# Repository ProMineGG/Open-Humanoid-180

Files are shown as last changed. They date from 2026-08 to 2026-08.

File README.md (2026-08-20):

# Open-Humanoid-180





[Дорожная карта проекта](https://github.com/ProMineGG/Open-Humanoid-180/issues/1)
[Contributing](CONTRIBUTING.md)

*Читать на других языках: [English](README.en.md)*

**Открытый проект двуногого гуманоидного робота ростом 180 см — на доступных компонентах, самодельных волновых редукторах и распределённой вычислительной архитектуре.**

---

## Обзор

Цель проекта — создать полноразмерного (180 см, ~60 кг) шагающего робота с бортовым ИИ (зрение + языковые модели) при бюджете около **350 тыс. рублей**.  
Вместо дорогих промышленных приводов используются:

- Самодельные **двухступенчатые волновые редукторы с промежуточными телами качения (ПТК)** — стальные ролики от подшипников в качестве тел качения.  
- **BLDC-моторы** четырёх типов (6384, 5065, 5010, 3205) — всего 36 степеней свободы.
- **Ноутбук с RTX 3080** без корпуса — основной мозг (альтернатива дорогим специализированным модулям, обеспечивая большую доступность и производительность за цену).
- **Распределённая сеть управления:** ESP32-S3 как CAN-шлюз, AT32F403ACGU7 для низкоуровневого FOC, перепрошитые платы от гироскутеров для средних и базовых моторов.

Все механические детали рассчитаны на **литьё алюминия в самодельной печи** (угольный горн) или 3D-печать (PETG / PETG-CF) на Ender 3 V3 Plus.

---

## Основные характеристики

| Параметр | Значение |
| :--- | :--- |
| Рост / Вес | 180 см / ~60 кг (целевой) |
| Степени свободы | 36 (6 мощных + 7 средних + 10 базовых + 13 слабых) |
| Аккумулятор | 10S Li‑NMC (SK 3.7В 80.5Ач) + JK Smart BMS (200А) |
| Основная шина питания  | 33-41В(вольтаж на ячейку ограничен 3.3-4.1В) |
| Вторичные напряжения | 24В (SimpleFOCmini), 20 В (ноутбук), 5 В (логика + экран) |
| Вычисления | Ноутбук Lenovo L7 / R9 / RTX 3080 / 32GB / 1TB (Ubuntu 22.04 + RT‑Preempt) |
| Узел реального времени | ESP32‑S3 (CAN-шлюз, сбор IMU, расширение ввода/вывода) |
| Контроллеры моторов | ODrive3.6 (x3), Платы гироскутеров (x9), SimpleFOCMini (x13) |
| Связь | CAN (STM32F103C8T6+SN65HVD230) |
| Датчики | 13× BMI160, 1× ICM-20948, 10× FSR402, 4× тензодатчика XNQJALYCY 100кг |
| Бюджет (август 2026) | ~329 043 ₽ (подробно в [BOM.ru.md](./docs/BOM.ru.md)) |
| Лицензия | **GNU GPLv3** (код, CAD, схемы) |

---

## Компоновка приводов и редукторы

Механика построена по модульному принципу. Распределение моторов по суставам:

- **Ноги (8 приводов):**  
  – **6× 6384 120KV** (редукция 1:100) – по 2 на каждый тазобедренный сустав (сгибание/отведение) + по 1 на колено.  
  – **2× 5010 360KV** (редукция 1:64) – вращение в тазобедренных суставах (по одному на ногу).

- **Корпус и шея (4 привода):**  
  – **1× 5065 140KV** (1:64) – наклон корпуса (поясница).  
  – **3× 3205 110KV** (1:42) – шея (2 наклона + 1 поворот).

- **Руки (24 привода):**  
  – **4× 5065 140KV** (1:64) – плечи (по 2 на руку: подъём и отведение).  
  – **2× 5010 360KV** (1:42) – плечи (вращение, по 1 на руку).  
  – **2× 5065 140KV** (1:64) – локти (сгибание, по 1 на руку).  
  – **2× 5010 360KV** (1:42) – локти (вращение предплечья, по 1 на руку).  
  – **4× 5010 360KV** (1:42) – запястья (по 2 на руку: сгибание/отведение, приводы вынесены в предплечья с тросами Боудена).  
  – **10× 3205 110KV** (1:42) – пальцы (по 5 на руку, сгибание).

**Итого:**  
- 6384 – 6 шт.  
- 5065 – 7 шт. (4 плечи + 2 локти + 1 поясница)  
- 5010 – 10 шт. (2 таз + 2 плечи вращ. + 2 локти вращ. + 4 запястья)  
- 3205 – 13 шт. (3 шея + 10 пальцев)

**Редукторы:**  
Самодельные **волновые передачи с роликами (ПТК)**.  
- Двухступенчатая схема; общие передаточные числа:  
  - 1:100 – для мощных (6384)  
  - 1:64 – для средних (5065) и базовых (5010) в тазобедренных суставах  
  - 1:42 – для слабых (3205) и базовых (5010) в плечах, локтях и кистях  
- Тела качения — стандартные стальные ролики от подшипников (дешёвые, износостойкие).  
- Корпуса отливаются из алюминия или печатаются из PETG CF/GF.

### Процесс производства редукторов (DIY Casting)

Для создания волновых редукторов алюминий предварительно переплавляется в очищенные слитки в самодельной печи.

<table align="center" border="0" cellpadding="5" cellspacing="0">
  <tr>
    <td valign="top">
      <table border="0" cellpadding="5" cellspacing="0">
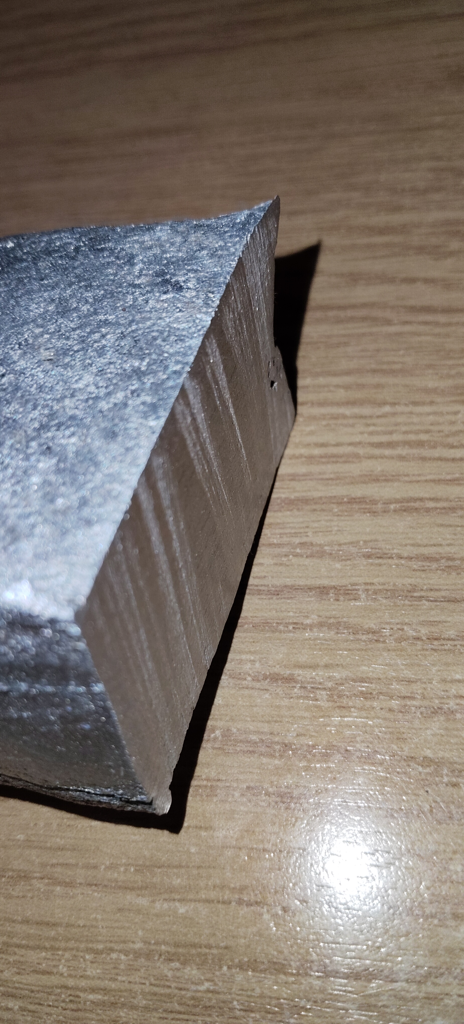
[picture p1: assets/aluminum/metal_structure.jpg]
Срез металла 1
        <tr><td></td></tr>
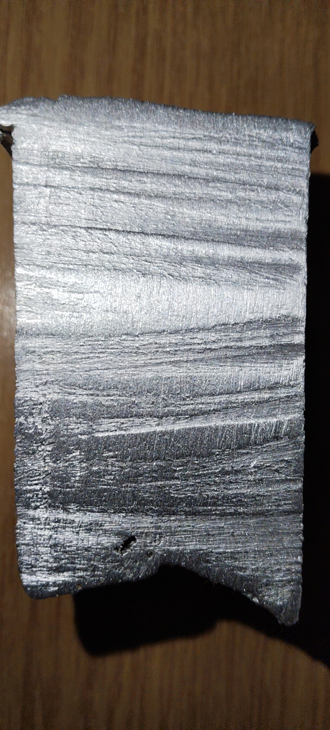
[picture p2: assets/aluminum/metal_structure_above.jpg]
Срез металла 2
        <tr><td></td></tr>
      </table>
    </td>
    <td valign="top">
      <table border="0" cellpadding="5" cellspacing="0">
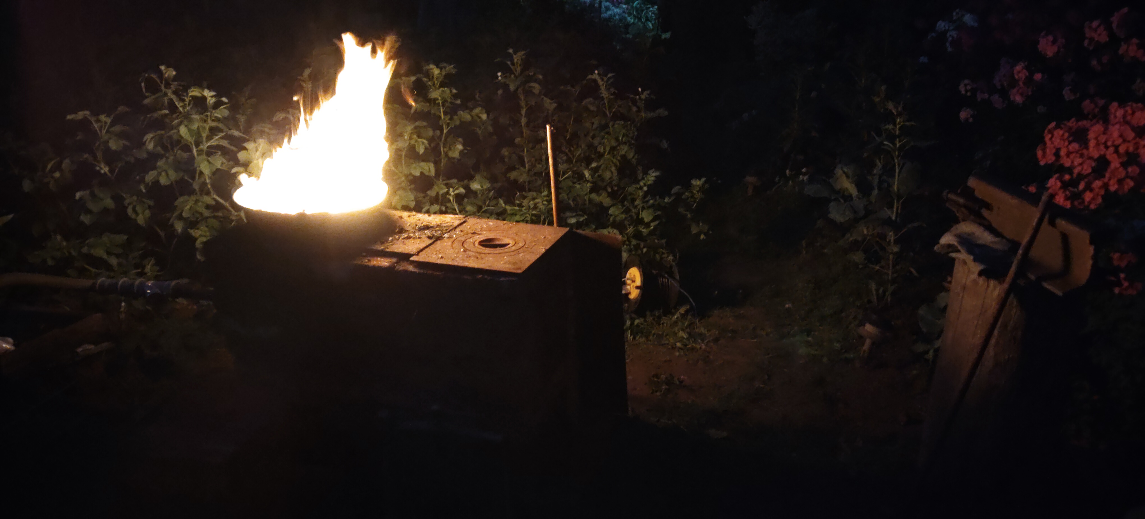
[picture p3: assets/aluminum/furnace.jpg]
Ночная печь
        <tr><td></td></tr>
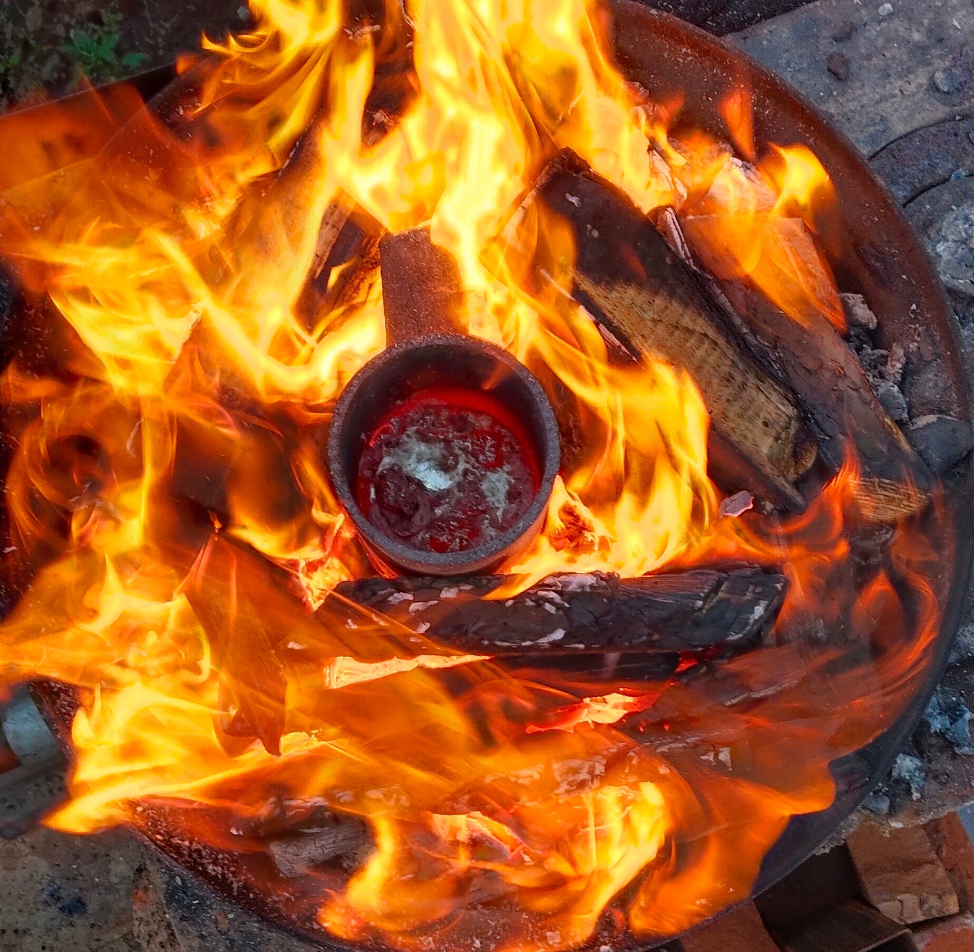
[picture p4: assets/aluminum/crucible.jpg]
Жидкий алюминий в тигле
        <tr><td></td></tr>
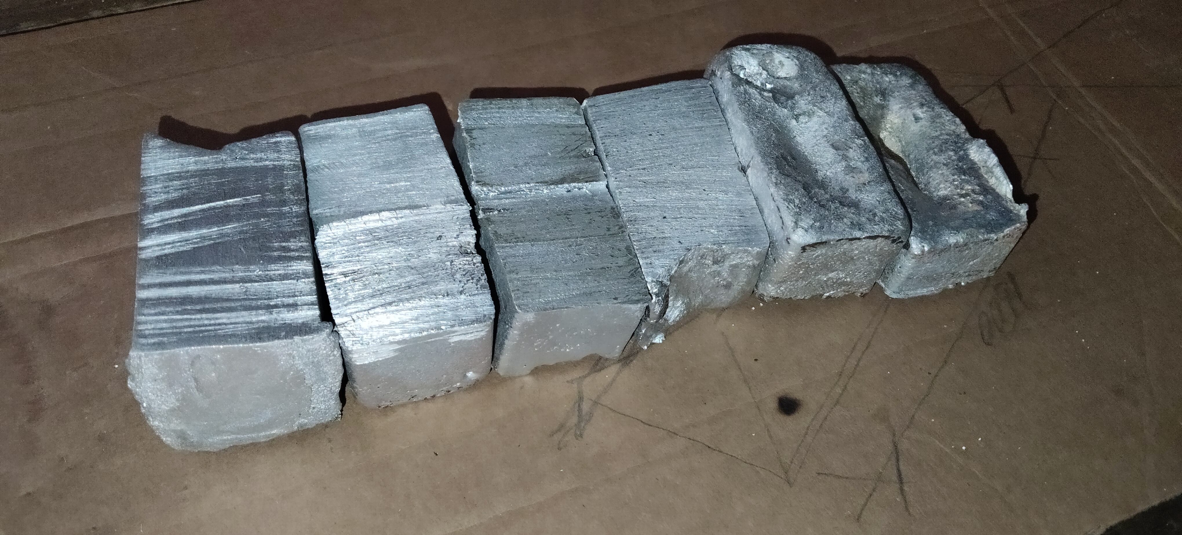
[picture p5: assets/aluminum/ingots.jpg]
Готовые слитки 1
        <tr><td></td></tr>
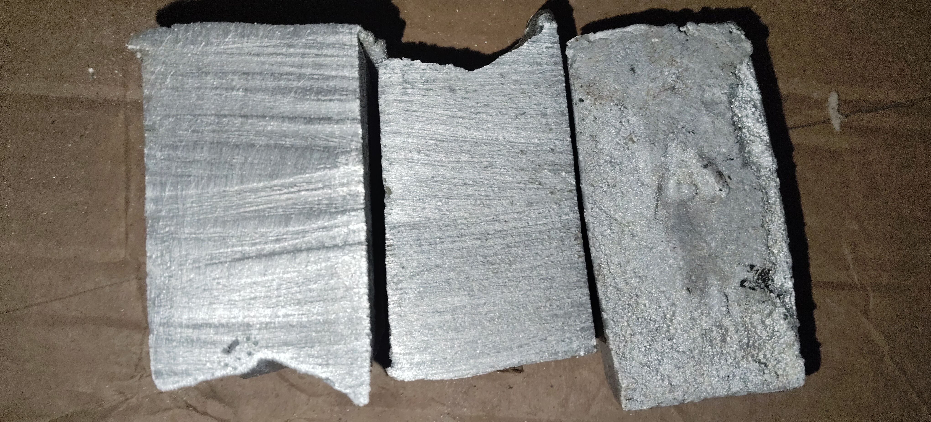
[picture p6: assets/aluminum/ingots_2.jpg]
Готовые слитки 2
        <tr><td></td></tr>
      </table>
    </td>
  </tr>
</table>

---

## Распределение питания и защита

- **Аккумулятор:** 10S Li‑NMC (SK 3.7В 80.5Ач, pouch‑ячейки) – высокая энергоёмкость при умеренном весе.  
- **BMS:** JK‑B2A24S20P (200А постоянный, поддержка 8-24S) с Bluetooth-мониторингом.  
- **Основная защита:** автоматический выключатель 200А на плюсовой линии.  
- **Блок предохранителей:** хаб ATO на 10 гнёзд – 40А для рук/торса, 25А для ноутбука и 5В-преобразователей, 10А для головы.  
- **Отдельные предохранители:** 3 одиночных держателя с предохранителей 80А – каждый для своего ODrive3.6 (питание напрямую от распределительных блоков).  
- **Распределительные блоки:** два блока на 250А (11 выводов) – плюсовая и минусовая шины.  
- **Конденсаторы на шине:** 10× 63В 4700 мкФ, 15× 35В 2200 мкФ – демпфируют выбросы рекуперации.  
- **Локальная фильтрация:** керамика 0.1 мкФ на каждой SPI/I2C-линии и плате драйвера для подавления ШИМ-помех, а также LC-фильтры помех после понижающий преобразователей 5в и 24в
- **Монтаж:** сигнальные неподвижные линии – экранированным кабелем МКЭШ, заземление экранов в одной точке (на минусовой распределительный блок) для исключения земляных петель. AWG30 в скрученной паре для CAN

Все DC‑DC преобразователи (1500W, 600W) выбраны **с кратным запасом** и работают **без активного охлаждения** – дополнительных вентиляторов для них здесь нет

---

## Архитектура вычислений и связи

### Уровни

1. **Верхний (ноутбук)**  
   Ubuntu 22.04 с ядром RT‑Preempt. Запускает ROS2, YOLO и VLM-модели (Qwen 3.5 9B / RT‑2X). Получает данные от ESP32 и выдаёт целевые движения.

2. **Средний (ESP32‑S3)**  
   Получает CAN от STM32F103C8T6 с информацией от: 13× BMI160, 4× АЦП HX711 и массив FSR402. Сливает данные IMU в оценку ориентации и передаёт ноутбуку. Также является **CAN-шлюзом** для всех контроллеров моторов.

3. **Нижний (контроллеры суставов)**  
   – **ODrive3.6** (x3) – управляют 6 мощными моторами (6384) по CAN.  
   – **Платы гироскутеров** (x9) – каждая управляет 2 моторами (5065 или 5010). Итого 18 каналов, фактически задействовано 17 (7 средних + 10 базовых). У плат только **UART**, поэтому мы используем **AT32F403ACGU7/STM32F103C8T6** как UART‑to‑CAN мосты: один MCU опрашивает 2–3 платы гироскутера и ретранслирует данные на ESP32 через CAN.  
   – **SimpleFOCMini** (x13) – управляют 13 слабыми моторами (3205) напрямую с AT32F403ACGU7 (они же читают SPI-энкодеры).  
   – **Энкодеры:** 36× MT6826S – 14‑разрядные абсолютные, интерфейс SPI.
   – **STM32F103C8T6** (x10) – опрашивает 13× BMI160, 4× АЦП HX711 и массив FSR402 (через мультиплексор CD74HC4067), и преобразует все аналоговые/I2C/SPI/UART сигналы в CAN, оправляет на ESP32‑S3 через SN65HVD230.

### Сенсорная сеть

- **IMU-узлы:** 13× BMI160 и 1× ICM-20948  – подключены к STM32F103C8T6 по SPI.
- **Тактильные:** 10× FSR402 на пальцах → аналоговый мультиплексор CD74HC4067 → АЦП STM32F103C8T6.  
- **Сила стоп:** 4× тензодатчика XNQJALYCY 100 кг (по 2 на стопу) → HX711 → STM32F103C8T6.

---

## Статус проекта (Август 2026)

- [x] Полный подбор компонентов и расчёт сметы (см. `/docs/BOM.ru.md`).
- [x] Предварительная схема питания и разводки.
- [x] Тест литья алюминия – успешно (плавка лома в угольном горне с раскислением солью/содой).
- [ ] 3D-принтер (Ender 3 V3 Plus) и материалы в наличии.
- [ ] CAD-модели всех редукторов (в работе).
- [ ] Первый прототип одного сустава (активная разработка CAD-моделей, расчёт допусков и подбор бюджетных поставщиков; закупка начнётся после завершения 3D-моделирования).
- [ ] Прошивка для ESP32 и AT32F403ACGU7 (будет опубликована после отладки).
- [ ] URDF-модель для Gazebo.

---

## Структура репозитория

* [`BOM.ru.md`](./docs/BOM.ru.md) – Полная смета с ценами, количествами и ссылками на Ozon / AliExpress / Avito.
* [`power_schematic.ru.md`](./docs/power_schematic.ru.md) – Схема питания, распределение предохранителей (автомат 200А, ATO-хаб, отдельные 80А для ODrive), разводка клеммников WAGO.
* [`weight_budget.ru.md`](./docs/weight_budget.ru.md) – Развесовка по узлам, оценка центра масс, выбор материалов (алюминий / PETG / PETG‑CF).
* [`docs/kinematics.ru.md`](./docs/kinematics.ru.md) – Кинематическая схема (распределение осей по суставам, типы моторов).

* [`in progress/motor_selection.ru.md`](./docs/in%20progress/motor_selection.ru.md) – Расчёты приводов: выбор KV, моменты на суставах, обоснование редукций *(в разработке)*.
* [`in progress/reducer_design.ru.md`](./docs/in%20progress/reducer_design.ru.md) – Инженерные детали двухступенчатого волнового редуктора с роликами (ПТК) *(в разработке)*.
* [`in progress/casting_aluminium.ru.md`](./docs/in%20progress/casting_aluminium.ru.md) – Пошаговое руководство по литью алюминия в домашних условиях *(в разработке)*.
* [`in progress/assembly_guide.ru.md`](./docs/in%20progress/assembly_guide.ru.md) – Последовательность сборки, прокладка жгутов, правила экранирования *(в разработке)*.
* [`in progress/alternative_parts.ru.md`](./docs/in%20progress/alternative_parts.ru.md) – Бюджетные альтернативы и заметки по модификации ESC *(в разработке)*.

* [`hardware/STL/`](./hardware/STL/) – 3D-модели для печати (PETG – корпуса, PA12‑CF – обоймы редукторов, TPU – подошвы стоп).
* [`hardware/CAD/`](./hardware/CAD/) – Исходники CAD (FreeCAD / STEP) – в разработке.
* [`software/esp32_firmware/`](./software/esp32_firmware/) – Код ESP32‑S3: опрос IMU (SPI), CAN-шлюз, логика UART‑to‑CAN моста.
* [`software/at32_firmware/`](./software/at32_firmware/) – Прошивка AT32F403ACGU7: драйвер SimpleFOCMini, чтение энкодеров MT6826S (SPI), связь с ESC по UART.
* [`simulation/urdf/`](./simulation/urdf/) – URDF/XACRO модель для Gazebo / Isaac Sim (будет добавлена).

---

## Участие и лицензия

Приглашаются соавторы с опытом в:

- **Управлении ROS2** и **моделировании URDF/XACRO**.
- **Настройке низкоуровневого FOC** (особенно ограничений тока для низкоиндуктивных моторов).
- **Симуляции** (Gazebo / Isaac Sim) для разработки походки.
- **Механическом CAD** (FreeCAD, Fusion 360) – нужна помощь в переводе эскизов в готовые модели.

Подробные инструкции по участию — в [CONTRIBUTING.md](CONTRIBUTING.md).

Заводите Issues и Pull Requests. Для обсуждений скоро создадим Telegram-канал.

**Лицензия:** Все код, CAD и схемы распространяются под **GNU GPLv3** – коммерческое использование разрешено только при условии, что производная работа остаётся полностью открытой.

---

*Сделано с помощью стандартных инструментов, литров технического кофе и упрямого нежелания покупать дорогие проприетарные запчасти.*

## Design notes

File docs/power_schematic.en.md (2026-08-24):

# Power Distribution Schematics — Open-Humanoid-180

This document outlines the complete power distribution architecture for the robot — from the battery pack to every actuator, computing unit, and sensor.

---

## General Structure

- **Battery Pack:** 10S Li‑NMC (SK 3.7V 80.5Ah, pouch‑cells) — nominal 37V, max 42V (cell voltage limited to 3.3–4.1V via BMS for longevity).
- **BMS:** JK‑B2A24S20P (200A continuous, 8‑24S support) with Bluetooth monitoring.
- **Main Protection:** 2‑Pole (2P) DC automatic circuit breaker rated at 200A. Breaks both positive and negative rails simultaneously.
- **Distribution:** Two 250A power distribution blocks (11 terminals each) — positive and negative busbars.
- **Secondary Protection:** 10‑slot ATO fuse hub for all load lines except ODrive controllers.
- **Dedicated ODrive Protection:** 3 single‑slot fuse holders with 80A fuses (one for each ODrive3.6 board).
- **Voltages:** 33–41V (motors 6384, 5065, 5010), 24V (SimpleFOCmini), 20V (laptop), 5V (logic and display).

---

## Battery Pack Assembly

### Cells
- 10 Li‑NMC 3.7V 80.5Ah pouch cells (SK) connected in series (**10S1P**).
- Nominal voltage: **37V**, maximum voltage at full charge: **42V**.
- Cell Interconnection: Cell power tabs must be carefully bent and overlapped using solid copper busbar links, secured tightly with M6 bolts and split lock washers (Grower washers) to prevent loosening from walking vibrations. The cells must be compressed inside a rigid structural frame to prevent swelling.

### Inter‑Module Jumpers & Main Leads
- **Cable:** Flexible heavy‑gauge wire **KOG1‑T 1×25 mm²** — used for routing main high‑current lines from cell tabs to the circuit breaker, BMS, and main distribution blocks.

### Battery‑to‑BMS and Breaker Wiring
- **Positive:** (+) → KOG1‑T 1×25 mm² → **Input of the 1st pole of the 200A 2P Breaker** → Breaker Output → 250A Positive Distribution Block.
- **Negative:** (–) → KOG1‑T 1×25 mm² → BMS (–) → BMS Output → **Input of the 2nd pole of the 200A 2P Breaker** → Breaker Output → 250A Negative Distribution Block.
- **Layout Note:** Routing the main 25 mm² KOG1‑T bus through the moving axes of the leg joints requires strict verification in CAD. Any potential layout modifications or swapping to high‑flex silicone equivalents are frozen until the 3D‑modeling phase.

### Balance Leads
- **Cable:** 30 AWG silicone wire — 10 m.
- **Terminals:** M6 ring terminals (8 pcs) — mounted directly under the tab fastening bolts.
- Connected directly to the BMS (configured to 10S operation).

### Fasteners & Insulation
- M6 flanged bolts and nuts with serration — 16 pcs.
- M6 Grower washers — 16 pcs.
- 12 mm dual‑wall adhesive‑lined heat shrink tubing — 1 m.
- Kapton / high‑temperature insulation tape — 1 pc.

---

## Main Power Bus (33–41V)

### Primary Distribution
Past the 200A 2‑pole circuit breaker, the main current splits into:
- **Positive Busbar:** 250A, 11‑terminal block.
- **Negative Busbar:** 250A, 11‑terminal block.

### ATO Fuse Hub (10 Slots)
5 dual‑core **KGTP‑HL 2×4 mm²** cables (10 m total) link the positive busbar to the fuse hub inputs:
- On the busbar side, the two cores are twisted together (forming an 8 mm² equivalent) and crimped into a single pin cord‑end terminal (NSHVI).
- On the fuse hub side, the cores separate into two 6.3 mm female spade quick‑disconnect terminals.
- 5 cables × 2 cores = 10 individual fuse inputs.

### Load Lines Leaving the ATO Hub

| Line | Load / Sub‑system | Fuse Rating | Cable Type (Hub to Load) |
| :--- | :--- | :---: | :--- |
| 1 | 1500W Step‑Down Converter → Laptop (20V) | 25A | KGTP‑HL 2×1.5 |
| 2 | 600W Step‑Down Converter → LED Screen (5V) | 25A | KGTP‑HL 2×1.5 |
| 3 | 300W Step‑Down Converter → Central Logic Power Hub (5V) | 25A | KGTP‑HL 2×1.5 |
| 4 | Left Arm — 5‑pin WAGO terminal (SimpleFOC supply) | 40A | KGTP‑HL 2×4 |
| 5 | Right Arm — 5‑pin WAGO terminal (SimpleFOC supply) | 40A | KGTP‑HL 2×4 |
| 6 | Torso/Abdomen — 3‑pin WAGO terminal | 40A | KGTP‑HL 2×4 |
| 7 | Head/Neck — 3‑pin WAGO terminal | 10A | KGTP‑HL 2×1.5 |

**Important Notice:** All lines powering the ODrive3.6 controllers **bypass the main ATO fuse hub completely** — see the dedicated section below.

---

## Dedicated ODrive3.6 Protection (3 Units)

Each ODrive3.6 controller is powered via an independent inline fuse holder populated with an 80A fuse.

- **Circuit:** Positive Busbar (250A) → KGTP‑HL 2×4 → **80A Fuse Holder** → XT90 Connector → **ODrive (Vin)**.
- **Negative:** ODrive (GND) → KGTP‑HL 2×4 → Negative Busbar (250A).
- **Cable Length:** ~1.5–2 m per run.
- **Quantity:** 3 complete matching wiring runs (Left Leg, Right Leg, Lower Back/Waist).

---

## Secondary & Logic Wiring

- **KGTP‑HL 2×1.5 (10 m):** Stationary internal housing wiring. Runs from WAGO terminal blocks to hoverboard driver boards, to buck converter inputs, and from converters to the laptop, LED screen, and SimpleFOCMini boards.
- **MGSHV 0.35 mm² (20 m):** Local point‑to‑point interconnect wiring, prototyping jumpers, and low‑current power routing inside enclosed hub boxes and control boards.
- **MKEShng(A)‑LS 7×0.35 (20 m):** Shielded multi‑core trunk line for SPI sensor buses. Used to route signals from the 13 BMI160 IMU modules, MT6826S magnetic joint encoders, and outputs from the CD74HC4067 analog multiplexers hidden inside the hands. 2 internal wires are dedicated to a localized +5V and GND logic power transit.
- **MKEShng(А)‑LS 5×0.35 (15 m):** High‑speed transit for inter‑board communication (CAN‑bus linking AT32/STM32 hubs to the central ESP32‑S3 / UART lines). Also handles the digital output data coming from the HX711 ADC boards installed inside the feet (digitizing the dual 100 kg load cells). 2 internal wires are dedicated to a localized +5V and GND logic power transit.
- **MKEShng(А)‑LS 2×0.35 (5 m):** Simplified connections for isolated limit switches, foot contact bumpers, and the physical Emergency Stop (E‑Stop) master button.
- **Shield Grounding:** The braided copper shielding of all MKESh cables must be tied to a single, common ground point on the main negative distribution block. This prevents high‑frequency PWM switching noise generated by the FOC motor drivers from introducing corruption into the logic sensor buses.

---

## Actuator Phase Wiring (Super‑Flexible Silicone AWG)

All motor phase wiring running through moving joint pivots utilizes high‑strand silicone insulation to eliminate mechanical spring‑back forces against the PTK wave reducers and safeguard the copper lines against fatigue snapping.

| Actuator Motor | Cable Type | Total Strand Metrage | Installation & Routing Notes |
| :--- | :--- | :---: | :--- |
| **6384 120KV (6 pcs)** <br>Heavy‑duty leg joints | Silicone **14 AWG** (2.08 mm²) | ~25 m | Twisted into 3‑phase tight braids; routed via a loose U‑shaped loop along the exterior curve of the hinge joints. |
| **5065 140KV (7 pcs)** <br>Pelvis & hip actuators | Silicone **14 AWG** (2.08 mm²) | ~25 m | Harmonized with 6384 gauge. Guarantees ampacity margin under continuous FOC hold loads supporting the upper body. |
| **5010 330KV (10 pcs)** <br>Mid‑tier arm actuators | Silicone **20 AWG** (0.52 mm²) | 50 m | Phases assembled into 3‑color matching braids. Rated up to 11A continuous. |
| **3205 110KV (13 pcs)** <br>Finger servos & neck | Silicone **26 AWG** (0.13 mm²) | 50 m | Ultra‑thin phase strands. Minimizes wire cluster bulk inside the palms to feed 5 active fingers cleanly. |

---

## Capacitors and Filtering

- **Local Driver Protection:** 10× 4700 µF / 63V capacitors placed near ODrive 3.6 and hoverboard driver boards; 13× 4700 µF / 35V capacitors near SimpleFOCMini boards.
- **Buck Output Filters:** LC filters on the 5V logic rail (4A) and the 24V SimpleFOCmini rail (20A).
- **HF Decoupling:** 0.1 µF (104 ceramic) bypass capacitors placed immediately at the power pins of each SimpleFOCMini, MT6826S, and BMI160 chip.

---

## Connectors and Hard Components

| Component | Qty | Intended Application / Connection Node |
| :--- | :---: | :--- |
| 250A Distro Block (11 terminals) | 2 | Primary + and – power distribution busbars in the torso |
| CD74HC4067 Multiplexer Board | 2 | Localized multiplexed sampling of FSR402 pressure pads inside the hands (1 per hand) |
| HX711 ADC Breakout Board | 2 | Localized digitizing of analog load cell signals inside the feet (1 per foot) |
| WAGO 221‑415 (5‑wire lever) | 6 | Secondary power distribution splits inside the arms and neck |
| WAGO 221‑413 (3‑wire lever) | 2 | Secondary power distribution splits inside the torso cavity |
| QS8P‑S (Anti‑Spark) |  1 pair  | Master manual battery disconnect plug situated upstream of the main breaker |
| XT90-S (Anti-Spark) | 4 pairs  | Quick‑disconnect points for transit power lines traveling from thighs to torso |
| XT90 (Standard pairs) | 6 pairs  | Main inputs for ODrive controllers and primary sub‑assembly interfaces |
| XT60/XT60h (Standard pairs) | 12 pairs | Input/output hooks for buck converters and hoverboard driver boards |
| XT30 (Standard pairs) | 5 pairs  | Power feeds to SimpleFOCMini modules and neck actuators |
| GX12 (5‑pin, panel‑mount pairs)  | 5 pairs  | Shielded low‑frequency signal interconnects between structural chassis blocks |
| JST‑XH 2.54 (Assorted Kit) | 1 | Micro‑crimping connectors for encoder and logic breakout lines (BMI160, MT6826S) |

---

## Protection Fuse Matrix Summary

| Protection Device | Qty | Physical Mounting Location | Rated Trip Current |
| :--- | :-: | :--- | :---: |
| DC 2‑Pole Circuit Breaker |  1  | Inline past the master QS8P plug; cuts (+) and (–) simultaneously | 200A |
| ATO Blade Fuse Hub |  1  | Positioned immediately downstream of the positive 250A block | 10 Slots Available |
| ATO Blade Fuse 40A |  4  | Protecting the Arm WAGO nodes and main Torso lines | 40A |
| ATO Blade Fuse 25A |  3  | Protecting Buck Converters (Laptop, 5V 600W, 5V 300W) | 25A |
| ATO Blade Fuse 10A |  1  | Protecting Head, Neck, and localized logic nodes | 10A |
| Inline Holder + ANL/MIDI 80A |  3  | Dedicated protection module placed immediately before each ODrive3.6 input | 80A |

---

## Cable Ledger Summary

| Cable Designation | Required Length | Supplier Target | Intended Routing Target |
| :--- | :---: | :---: | :--- |
| KOG1‑T 1×25 mm² | 3 m | Cable‑ES | Primary heavy‑current links from cells to BMS, 2P breaker, and main busbars |
| KGTP‑HL 2×4 | 10 m | Cable‑ES | Stationary high‑current runs feeding the ATO fuse block and local ODrive inputs |
| KGTP‑HL 2×1.5 | 10 m | Cable‑ES | Stationary runs feeding hoverboard inputs and buck converter lines |
| MKEShng(A)‑LS 7×0.35 | 20 m | Cable‑ES | Shielded SPI data runs (IMU modules, encoders, multiplexers) + embedded 5V logic |
| MKEShng(A)‑LS 5×0.35 | 15 m | Cable‑ES | Shielded CAN‑bus lines between hubs, UART lines, and digitized foot cell inputs |
| MKEShng(A)‑LS 2×0.35 | 5 m | Cable‑ES | Shielded isolated lines for hard limit switches, bumpers, and the E‑Stop loop |
| MGSHV 0.35 | 20 m | Cable‑ES | BMS cell balancing leads and tight point‑to‑point electronic enclosure wiring |
| Silicone 14 AWG (2.08 mm²) | 50 m |  Ozon (Kit) | High‑flex phase wires for high‑torque leg/pelvis BLDC motors (6384 and 5065) |
| Silicone 20 AWG (0.52 mm²) | 50 m |  Ozon (Kit) | High‑flex phase wires for arm BLDC actuators (10 units of 5010) |
| Silicone 26 AWG (0.13 mm²) | 50 m |  Ozon (Kit) | Ultra‑flex phase wires for micro finger BLDC actuators and neck servos (13 units of 3205) |
| Silicone 30 AWG (0.05 mm²) | 50 m |  Ozon (Kit) | CAN, balance leads, logic |

---

**Engineering Notice:** Designing and assembling a custom battery pack from pouch‑style cells requires a robust structural enclosure capable of maintaining exact mechanical compression on the cell faces, combined with an isolated, flame‑retardant bay. Cell tabs must be bolted using copper links and lock washers. If the pack is split or moved into the thigh regions during CAD, 3D cable spine simulations are mandatory to verify that the massive 25 mm² KOG1‑T conductors can clear the internal bend radius thresholds of the hip joints without locking up the degrees of freedom.

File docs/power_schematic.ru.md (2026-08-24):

# Схема распределения питания — Open-Humanoid-180

В этом документе описана полная архитектура распределения питания робота — от аккумулятора до каждого привода, вычислительного модуля и датчика.

---

## Общая структура

- **Аккумулятор:** 10S Li‑NMC (SK 3.7В 80.5Ач, pouch‑ячейки) — номинал 37В, макс. 42В(ограничиваем для долгой жизни до 3.3-4.1В на ячейку через BMS).
- **BMS:** JK‑B2A24S20P (200А постоянный, поддержка 8-24S).
- **Основная защита:** Двухполюсный (2P) автоматический выключатель 200А постоянного тока (DC). Рвёт одновременно плюсовую и минусовую магистрали.
- **Распределение:** два распределительных блока 250А (11 выводов каждый) — плюсовая и минусовая шины.
- **Вторичная защита:** хаб предохранителей ATO на 10 гнёзд для линий, кроме ODrive.
- **Отдельные предохранители для ODrive:** 3 одиночных держателя с предохранителями 80А (каждый на свой ODrive3.6).
- **Напряжения:** 33–41В (моторы 6384, 5065, 5010), 24В(SimpleFOCmini), 20В (ноутбук), 5В (логика и экран).

---

## Сборка батарейного блока

### Ячейки
- 10 ячеек Li‑NMC 3.7В 80.5Ач (SK) соединены последовательно **10S1P**.
- Номинальное напряжение: **37В**, макс. при полном заряде: **42В**.
- Соединение ячеек: силовые выводы (табы) аккуратно загибаются и соединяются внахлест через медные шины-перемычки болтовым зажимом М6 с обязательным использованием шайб Гровера (для защиты от раскручивания при вибрациях). Пакеты фиксируются в общем каркасе с прижимом.

### Межблочные перемычки и силовые выводы АКБ
- **Кабель:** Силовой гибкий провод **КОГ1-Т 1×25 мм²** — используется для вывода силовых концов от табов ячеек до автомата, BMS и распределительных блоков.

### Проводка от батареи к BMS и автомату
- **Плюс:** (+) → КОГ1-Т 1×25 мм² → **Вход 1-го полюса автомата 200А (2P)** → Выход автомата → распределительный блок 250А (+).
- **Минус:** (–) → КОГ1-Т 1×25 мм²² → BMS (–) → Выход BMS → **Вход 2-го полюса автомата 200А (2P)** → Выход автомата → распределительный блок 250А (–).
- **Примечание по компоновке:** Проводка магистрали КОГ1-Т 1×25 мм² через подвижные оси ног требует жесткой проверки в CAD. Возможное изменение топологии или замена на силиконовые аналоги заморожены до этапа 3D-моделирования.

### Балансировочные провода
- **Кабель:** 30 AWG — 10 м.
- **Клеммы:** кольцевые М6 (8 шт) — устанавливаются под крепежные болты табов.
- Подключаются к BMS (настраивается на 10S).

### Крепёж и изоляция
- Гайки и болты фланцевые М6 с насечкой — 16 шт.
- Шайбы Гровера М6 — 16 шт.
- Термоусадка 12 мм (с клеем) — 1 м.
- Каптоновый / высокотемпературный изоляционный скотч — 1 шт.

---

## Основная шина питания (33-42В)

### Первичное распределение
После двухполюсного автомата 200А питание идёт на:
- **Плюсовой блок:** 250А, 11 выводов.
- **Минусовой блок:** 250А, 11 выводов.

### Хаб предохранителей (10 гнёзд ATO)
5 кабелей **КГТП‑ХЛ 2×4 мм²** (10 м) соединяют плюсовой блок со входами хаба:
- На стороне распределителя жилы скручиваются (эквивалент 8 мм²) → одна гильза НШВИ.
- На стороне хаба жилы разделяются → две клеммы‑мамы 6.3 мм.
- 5 кабелей × 2 жилы = 10 входов.

### Линии нагрузки от хаба ATO

| Линия | Нагрузка | Предохранитель | Кабель от хаба до нагрузки |
| :---- | :--- | :---: | :--- |
| 1 | Понижайка 1500W → ноутбук (20В) | 25А | КГТП‑ХЛ 2×1.5 |
| 2 | Понижайка 600W → LED‑экран (5В) | 25А | КГТП‑ХЛ 2×1.5 |
| 3 | Понижайка 300W → центральный хаб питания логики (5В) | 25А | КГТП‑ХЛ 2×1.5 |
| 4 | Левая рука — WAGO 5‑конт. (Питание SimpleFOC) | 40А | КГТП‑ХЛ 2×4 |
| 5 | Правая рука — WAGO 5‑конт. (Питание SimpleFOC) | 40А | КГТП‑ХЛ 2×4 |
| 6 | Туловище/живот — WAGO 3‑конт. | 40А | КГТП‑ХЛ 2×4 |
| 7 | Голова/шея — WAGO 3‑конт. | 10А | КГТП‑ХЛ 2×1.5 |

**Важно:** линии ODrive3.6 **не проходят через хаб** — см. отдельный раздел.

---

## Отдельная защита ODrive3.6 (три шт.)

Каждый ODrive3.6 получает питание через отдельный держатель с предохранителем 80А.

- **Цепь:** Плюсовой блок 250А → КГТП‑ХЛ 2×4 → **держатель 80А** → XT90 → **ODrive (Vin)**.
- **Минус:** ODrive (GND) → КГТП‑ХЛ 2×4 → минусовой блок 250А.
- **Длина кабеля:** ~1.5–2 м.
- **Кол-во:** 3 комплекта (левая нога, правая нога, поясница).

---

## Вторичная проводка и Логика

- **КГТП‑ХЛ 2×1.5 (10 м):** Стационарная внутренняя разводка. От WAGO к платам гироскутеров, к понижайкам (вход), от понижаек к ноутбуку, LED‑экрану, SimpleFOCMini.
- **МГШВ 0.35 мм² (20 м):** Локальный межплатный монтаж, перемычки и разводка питания внутри закрытых корпусов хабов и управляющих плат.
- **МКЭШнг(А)‑LS 7×0.35 (20 м):** Экранированная почти неподвижная магистраль для датчиков SPI. Используется для подключения 13 модулей IMU (BMI160), магнитных энкодеров суставов MT6826S и выходов аналоговых мультиплексоров CD74HC4067 из кистей рук. 
- **МКЭШнг(А)‑LS 5×0.35 (15 м):** Скоростной транзит межплатного интерфейса (CAN-шина между AT32 и ESP32-S3 / UART). Также используется для съема цифрового сигнала с плат АЦП HX711, установленных локально в стопах (от 2х тензодатчиков по 100 кг). 2 жилы выделены под транзит +5В и GND слаботочного питания.
- **МКЭШнг(А)‑LS 2×0.35 (5 м):** Подключение одиночных концевиков, бамперов стоп и кнопки аварийной остановки E-Stop.
- **Заземление экранов:** Медные плетеные экраны всех кабелей МКЭШ заземляются строго в одной общей точке на центральном минусовом блоке для гашения ШИМ-наводок от FOC-драйверов, моторов и понижаек

---

## Проводка фаз моторов (Супергибкий Силикон AWG)

Все фазные кабели подвижных суставов переведены на силиконовую изоляцию для обеспечения нулевого упругого сопротивления волновым редукторам с ПТК и защиты жил от циклического излома.

| Мотор | Кабель | Общий метраж жилы | Особенности монтажа |
| :--- | :--- | :---: | :--- |
| **6384 120KV (6 шт)** <br>Тяжелые приводы ног | Силикон **14 AWG** (2.08 мм²) | ~25 м | Скручивается в косички по 3 фазы, укладывается широкой U-образной петлей по внешней стороне сустава. |
| **5065 140KV (7 шт)** <br>Приводы таза и корпуса | Силикон **14 AWG** (2.08 мм²) | ~25 м | Унифицирован с 6384. Обеспечивает запас по току под FOC-нагрузкой удержания торса. |
| **5010 330KV (10 шт)** <br>Средние приводы рук | Силикон **20 AWG** (0.52 мм²) | 50 м (бокс) | Фазы собираются в трехцветные косички из бокса. Ток до 11А, легкий изгиб для средних суставов. |
| **3205 110KV (13 шт)** <br>Пальцы рук и шея | Силикон **26 AWG** (0.13 мм²) | 50 м (бокс) | Ультратонкие фазные нити. Минимизируют объем жгута внутри кисти руки для 5 пальцев. |

---

## Конденсаторы и фильтрация

- **Локальная защита драйверов:** 10× 63V 4700 мкФ рядом с ODrive 3.6 и платами гироскутеров, 13× 35V 4700 мкФ рядом с SimpleFOCmini
- **Фильтры выходов понижаек:** LC-фильтры помех на 4А(понижайка 5В на логику) и 20А(понижайка 24В на SimpleFOCmini).
- **ВЧ‑развязка:** 0.1 мкФ (104) на каждом SimpleFOCMini, MT6826S, BMI160.

---

## Разъёмы и компоненты

| Компонент | Кол‑во | Назначение |
| :--- | :---: | :--- |
| Распредблок 250А (11 выводов) | 2 | + и – шины в торсе |
| Мультиплексор CD74HC4067 | 2 | Локальный опрос датчиков давления FSR402 в кистях рук (по 1 шт на руку) |
| Плата АЦП HX711 | 2 | Локальная оцифровка тензодатчиков в стопах (по 1 шт на стопу) |
| WAGO 221‑415 (5‑конт.) | 6 | Распределение питания рук и шеи |
| WAGO 221‑413 (3‑конт.) | 2 | Распределение питания торса |
| QS8P‑S (Anti‑Spark) | 1 пара | Главный разъем ручного отключения АКБ перед автоматом защиты |
| XT90-S (Anti-Spark) | 4 пары | Разъемы силового транзита питания из бёдер в таз (при разнесенной компоновке) |
| XT90 (пары) | 6 пар | Локальные подключения ODrive и силовых блоков |
| XT60/XT60h (пары) | 12 пар | Понижайки, платы гироскутеров |
| XT30 (пары) | 5 пар | SimpleFOCMini, драйверы шеи |
| GX12 (5‑pin, пары) | 5 пар | Сигнальные межплатные стыки |
| JST‑XH 2.54 (набор) | 1 | Коммутация слаботочных датчиков |

---

## Сводка по защите

| Устройство | Кол‑во | Место | Номинал |
| :--- | :---: | :--- | :--- |
| Автомат DC 2P | 1 | После QS8P, рвёт (+) и (–) | 200А |
| Хаб ATO | 1 | После плюсового блока | 10 гнёзд |
| ATO 40А | 4 | Руки, торс | 40А |
| ATO 25А | 3 | Понижайки (ноутбук, 5В 600W, 5В 300W) | 25А |
| ATO 10А | 1 | Голова/шея | 10А |
| Одиночный держатель + 80А | 3 | Перед каждым ODrive3.6 | 80А |

---

## Сводка по кабелям

| Кабель / Маркоразмер | Длина | Источник закупки | Назначение |
| :--- | :---: | :---: | :--- |
| КОГ1-Т 1×25 мм² |  3 м  | Cable-ES | Главные силовые трассы от АКБ к BMS, 2P автомату и распредблокам |
| КГТП‑ХЛ 2×4 | 10 м  | Cable-ES | Неподвижные трассы к хабу ATO и платам ODrive |
| КГТП‑ХЛ 2×1.5 | 10 м  | Cable-ES | Неподвижное питание плат гироскутеров, входов DC-DC |
| МКЭШнг(А)‑LS 7×0.35 | 20 м  | Cable-ES | Сигналы SPI (IMU, энкодеры, мультиплексоры) + попутное 5В |
| МКЭШнг(А)‑LS 5×0.35 | 15 м  | Cable-ES | CAN-шины хабов, UART, цифровой выход HX711 + попутное 5В |
| МКЭШнг(А)‑LS 2×0.35 |  5 м  | Cable-ES | Трассы концевиков, бамперов и кнопки E-Stop |
| МГШВ 0.35 | 20 м  | Cable-ES | Балансиры BMS, внутренний монтаж электронных блоков |
| Силикон 14 AWG (2.08 мм²) | 50 м  | Ozon (набор) | Фазы тяжелых BLDC моторов ног и таза (6384 и 5065) |
| Силикон 20 AWG (0.52 мм²) | 50 м  | Ozon (набор) | Фазы средних BLDC моторов рук (10 шт 5010) |
| Силикон 26 AWG (0.13 мм²) | 50 м  | Ozon (набор) | Фазы мелких BLDC моторов пальцев и шеи (13 шт 3205) |
| Силикон 30 AWG (0,05 мм²) | 50 м  | Ozon (набор) | CAN, балансировочные провода, логика |

---

**Примечание:** Сборка батареи из pouch‑ячеек требует жесткого каркаса с прижимом и огнеупорного отсека. Соединение табов выполняется болтовым крепежом через медные шины-перемычки. При переносе ячеек в бедра требуется обязательное моделирование траектории сплайнов силовых кабелей КОГ1-Т 1×25 мм² в CAD для исключения заклинивания шарниров ног.

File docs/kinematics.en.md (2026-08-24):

# Open-Humanoid-180 – Kinematic Scheme

## General Specifications
- **Height:** 180 cm
- **Weight:** ~60 kg
- **Total Degrees of Freedom (DoF):** 36
- **Actuators:** 36 (one BLDC motor per DoF)
- **Motor types:**
  - High‑power: 6384 120KV – 6 units
  - Medium: 5065 140KV – 7 units
  - Basic: 5010 360KV – 10 units
  - Low‑power: 3205 110KV – 13 units
- **Gearboxes:** Harmonic (or cycloidal) drives with reduction ratios:
  - 1:100(1:10+1:10) – for high‑power motors
  - 1:64(1:8+1:8) – for medium motors and basic motors in the hip
  - 1:42(1:7+1:6) – for low‑power motors and basic motors in shoulders, elbows and wrists

---

## Joint Distribution

### Lower Limbs – 8 DoF (6 high‑power + 2 basic)

| Joint | DoF | Motor Type |
|---|-----|---|
| Left hip | 3 (flexion‑extension, abduction‑adduction, rotation) | 2 high‑power + 1 basic |
| Right hip | 3 (flexion‑extension, abduction‑adduction, rotation) | 2 high‑power + 1 basic |
| Left knee | 1 (flexion‑extension) | 1 high‑power |
| Right knee | 1 (flexion‑extension) | 1 high‑power |

> **Note:** Feet are passive rounded cylinders with no moving joints.

---

### Torso – 4 DoF (1 medium + 3 low‑power)

| Joint | DoF | Motor Type |
|---|-----|---|
| Lumbar (waist) | 1 (forward‑backward tilt) | 1 medium |
| Neck | 3 (tilt, pan, roll) | 3 low‑power |

---

### Upper Limbs – 24 DoF (6 medium + 8 basic + 10 low‑power)

| Joint | DoF | Motor Type |
|---|-----|---|
| Left shoulder | 3 (elevation, abduction, rotation) | 2 medium + 1 basic |
| Right shoulder | 3 (elevation, abduction, rotation) | 2 medium + 1 basic |
| Left elbow | 2 (flexion‑extension + forearm rotation) | 1 medium + 1 basic |
| Right elbow | 2 (flexion‑extension + forearm rotation) | 1 medium + 1 basic |
| Left wrist | 2 (flexion‑extension, abduction‑adduction) | 2 basic |
| Right wrist | 2 (flexion‑extension, abduction‑adduction) | 2 basic |
| Left fingers (5) | 1 per finger (flexion) | 5 low‑power |
| Right fingers (5) | 1 per finger (flexion) | 5 low‑power |

> **Note:** Each finger has a single actuator providing basic grasping capability. Full anatomical articulation is not reproduced.

---

## Motor Summary

| Type | Quantity | Location |
|---|---|---|
| 6384 120KV (high‑power) | 6 | Hips (4) + knees (2) |
| 5065 140KV (medium) | 7 | Waist (1), shoulders (4), elbows (2) |
| 5010 360KV (basic) | 10 | Hips (2), shoulders (2), elbows (2), wrists (4) |
| 3205 110KV (low‑power) | 13 | Neck (3) + fingers (10) |

---

## Actuator Control
- **High‑power motors** are driven by **ODrive 3.6** controllers.
- **Medium and basic motors** are driven by **hoverboard mainboards** (running *hoverboard‑firmware‑hack‑FOC*).
- **Low‑power motors** use **SimpleFOCMini** boards (based on AT32F403ACGU7, with MS8313 driver).
- **Encoders:** All motors are equipped with **MT6826S** absolute magnetic encoders.
- **Central processing:** ESP32‑S3 acts as a gateway, while a laptop with an RTX 3080 handles high‑level computation.

---

## Power Supply
- **Battery:** 10S Li‑NMC, with a 200 A BMS.
- **Power distribution:** via DC‑DC converters and protective circuit breakers.

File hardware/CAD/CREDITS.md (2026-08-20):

# Источники 3D-моделей

Этот файл содержит информацию об авторстве всех 3D-моделей, используемых в проекте Open-Humanoid-180.

---

## Самостоятельно созданные модели (автор: Open-Humanoid-180)

Эти модели созданы автором проекта с нуля по даташитам и технической документации.  
Они распространяются под лицензией [CC-BY-SA 4.0](https://creativecommons.org/licenses/by-sa/4.0/).

| Модель | Файл в репозитории | Примечания |
| :--- | :--- | :--- |
| LiFePO₄ 60145 50Ah <br>_«не используется»_ | `power/lifepo4_60145.stp` | Создано в CATIA V5 по спецификации производителя. |
| MT6826S (магнитный энкодер) | `sensors/mt6826s.stp` | Модель QFN-корпуса 14-разрядного энкодера по даташиту. |

---

## Модели с GrabCAD / GitHub / других сайтов

Эти модели взяты с открытых сайтов в формате STEP/STP.

| Модель | Файл в репозитории | Автор | Источник |
| :--- | :--- | :--- | :--- |
| BLDC 6384 120KV | `motors/6384-120KV.step` | [LeoDJ](https://grabcad.com/leodj-1) | [GrabCAD](https://grabcad.com/library/6384-brushless-motor-1) |
| BLDC 5065 140KV | `motors/5065-140KV.step` | [Alex Mordue](https://grabcad.com/alex.mordue-1) | [GrabCAD](https://grabcad.com/library/cheap-5065-brushless-motor-1) |
| BLDC 3205 110KV | `motors/3205-110KV.step` | [Robin Fröjd](https://grabcad.com/robin.frojd-1) | [GrabCAD](https://grabcad.com/library/pm2805-gimbal-bldc-1) |
| BMI160 (6‑осевой IMU) | `sensors/bmi160.step` | [Kai Compton](https://grabcad.com/kai.compton-2) | [GrabCAD](https://grabcad.com/library/bmi160-imu-1) |
| QMC5883L (магнитометр) | `sensors/qmc5883l.step` | [Benas Griauzde](https://grabcad.com/benas.griauzde-1) | [GrabCAD](https://grabcad.com/library/gy-271-hmc5883l-triple-3-axis-digital-compass-magnetometer-sensor-module-1) |
| FSR402 (датчик давления) | `sensors/fsr402.step` | [M. Adel Ibrahim](https://grabcad.com/m.adel.ibrahim-1) | [GrabCAD](https://grabcad.com/library/fsr402-1) |
| HX711 (АЦП для тензодатчиков) | `sensors/hx711.STEP` | [AD Hietkamp](https://grabcad.com/ad.hietkamp-1) | [GrabCAD](https://grabcad.com/library/hx711-loadcell-amplifier-1) |
| Керамический конденсатор 104 | `sensors/ceramic_capacitor_104.step` | [TheElectronicsArchive](https://grabcad.com/theelectronicsarchive-1) | [GrabCAD](https://grabcad.com/library/ceramic-capacitor-104-1) |
| ODrive 3.6 (драйвер) | `drivers/odrive3.6.stp` | [tezeuz](https://grabcad.com/tezeuz-1) | [GrabCAD](https://grabcad.com/library/motor-driver-odrive-v3-6-1) |
| SimpleFOCMini (драйвер MS8313) | `drivers/simplefocmini.step` | [askuric](https://github.com/askuric) | [GitHub](https://github.com/simplefoc/SimpleFOCMini/tree/main) |
| ESP32-S3 N16R8 | `mcu/esp32-s3.step` | [David Scambell](https://grabcad.com/david.scambell-1) | [GrabCAD](https://grabcad.com/library/yd-esp32-s3-1) |
| ESP32-S3 GPIO Shield | `mcu/esp32-s3-shield.STEP` | [Serj Minin](https://grabcad.com/serj.minin-1) | [GrabCAD](https://grabcad.com/library/esp32-s3-44-v2-1) |
| CD74HC4067 (мультиплексор) | `mcu/cd74hc4067.stp` | [Umberto Arena](https://grabcad.com/umberto.arena-3) | [GrabCAD](https://grabcad.com/library/mux-16-channels-1) |
| TJA1050 (CAN-трансивер) | `mcu/tja1050.STEP` | [Luiz Fernando Martinelli](https://grabcad.com/luiz.fernando.martinelli-1)  | [GrabCAD](https://grabcad.com/library/tja1050-module-1) |
| TXS0108E (преобразователь уровней) | `mcu/txs0108e.step` | [Tim Treis](https://grabcad.com/tim.treis-1) | [GrabCAD](https://grabcad.com/library/txs0108e-logic-level-converter-8-channel-for-arduino-and-raspberry-pi-1) |
| JK Smart BMS B1A8S20P | `power/jk_bms_b1a8s20p.STEP` | [Дмитрий Левин](https://grabcad.com/07b2a22aae-1) | [GrabCAD](https://grabcad.com/library/bms-jikong-model-jk-b1a8s20p-1) |
| LM25116 300W 20A Buck | `power/buck_300w_lm25116.step` | [Ferd kris](https://grabcad.com/ferd.kris-1) | [GrabCAD](https://grabcad.com/library/dc-dc-step-down-buck-converter-cc-cv-300w-20a-1) |
| SZ-BK6012 600W Buck | `power/buck_600w_sz-bk6012.step` | [Sam Sim](https://grabcad.com/sam.sim-4) | [GrabCAD](https://grabcad.com/library/buck-converter-600w-dc12-75v-25a-1) |
| Автоматический выключатель 200А | `power/circuit_breaker_200a.STEP` | [Andrey Kovalev](https://grabcad.com/andrey.kovalev-13) | [GrabCAD](https://grabcad.com/library/circuit-breaker-s202-c32-abb-2) |
| Хаб предохранителей (12 гнёзд) | `power/fuse_holder_12slot.step` | [Refael Cohen](https://grabcad.com/refael.cohen-1) | [GrabCAD](https://grabcad.com/library/12-way-blade-fuse-holder-1) |
| Предохранитель ATO (стандарт) | `power/ato_fuse_standard.stp` | [SG](https://grabcad.com/sg) | [GrabCAD](https://grabcad.com/library/fuse-ato-atc-5-amp-1) |
| Распределительный блок 160А | `distribution/dbl160_distribution_block.step` | [Edson Leão](https://www.3dcontentcentral.com/Contributors.aspx?id=1025350) | [3D ContentCentral](https://www.3dcontentcentral.com/download-model.aspx?catalogid=171&id=1353218&partnumber=DBL160) *(Free for Commercial Use)* |
| XT30 (пара) | `connectors/xt30/` | [stuplja](https://grabcad.com/stuplja-1) | [GrabCAD](https://grabcad.com/library/xt30-female-connector-1)<br>[GrabCAD](https://grabcad.com/library/xt30-male-connector-1) |
| XT60 (пара) | `connectors/xt60/` | [Ahmet Berkay Yılmaz](https://grabcad.com/ahmet.berkay.yilmaz-1) | [GrabCAD](https://grabcad.com/library/xt60-female-1)<br>[GrabCAD](https://grabcad.com/library/xt60-male-2) |
| XT60H (пара) | `connectors/xt60h/` | [Nelson Stoldt](https://grabcad.com/nelson.stoldt-1) | [GrabCAD](https://grabcad.com/library/power-connectors-male-female-xt60h-mr60-mt60-1) |
| XT90 (пара) | `connectors/xt90/` | [Dennis Mazur](https://grabcad.com/dennis.mazur-1) | [GrabCAD](https://grabcad.com/library/xt90pb-m-f-1) |

---

## Лицензия

- **Модели автора проекта** (LiFePO₄ и MT6826S) распространяются под лицензией [CC-BY-SA 4.0](https://creativecommons.org/licenses/by-sa/4.0/).
- **Модели с GrabCAD / 3D ContentCentral** принадлежат их авторам и используются в проекте с указанием авторства (модель распределительного блока имеет пометку *Free for Commercial Use*).
- **CAD-сборки** (ассембли), созданные на основе этих моделей, распространяются под лицензией [CC-BY-SA 4.0](https://creativecommons.org/licenses/by-sa/4.0/) только в части, касающейся новой работы (компоновки и интеграции), при условии сохранения ссылок на оригинальных авторов.

---

*Если вы автор какой-либо модели и хотите изменить способ указания авторства или удалить модель из репозитория — напишите в Issues.*

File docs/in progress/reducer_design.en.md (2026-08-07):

# Wave Reducer with Rolling Elements (ПТК) Design — Open-Humanoid-180

> **Status:** work in progress.
>
> This document will cover the engineering details of the custom two‑stage wave reducer with intermediate rolling elements (bearing rollers).

## Planned Content

- Elliptical cam (wave generator) geometry for each reduction ratio (1:100, 1:65, 1:40).
- Sizing and selection of steel bearing rollers as rolling bodies.
- Raceway profile calculations for rigid housings.
- Cage (separator) design for 3D printing from PA12‑CF.
- Assembly tolerances and recommended clearances.
- Material choices: cast aluminium vs. PA12‑CF printed parts.

## Status

Completed so far:
- [x] Reducer type selection (wave reducer with rolling elements).
- [x] Reduction ratios defined for each joint type.
- [ ] CAD modelling (in progress).
- [ ] Cam profile calculations.
- [ ] Specific roller size selection.
- [ ] First prototype manufacturing and testing.

---

*Available now: [BOM.en.md](BOM.en.md), [power_schematic.en.md](power_schematic.en.md), [weight_budget.en.md](weight_budget.en.md)*

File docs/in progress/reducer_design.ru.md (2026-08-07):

# Проектирование волнового редуктора с ПТК — Open-Humanoid-180

> **Статус:** в разработке.
>
> В этом документе будут описаны инженерные детали самодельного двухступенчатого волнового редуктора с промежуточными телами качения (роликами).

## Планируемое содержание

- Геометрия эллиптического кулачка (генератора волн) для каждой редукции (1:100, 1:65, 1:40).
- Размеры и выбор стальных роликов (от подшипников) в качестве тел качения.
- Расчёт профиля беговых дорожек жёстких обойм.
- Конструкция сепаратора (печать из PA12‑CF).
- Допуски сборки и рекомендуемые зазоры.
- Материалы: алюминиевое литьё vs. печать PA12‑CF.

## Статус

На данный момент выполнены:
- [x] Выбор типа редуктора (волновой с ПТК).
- [x] Определение передаточных чисел для каждого типа сустава.
- [ ] CAD-моделирование (в процессе).
- [ ] Расчёт профилей кулачков.
- [ ] Выбор конкретных типоразмеров роликов.
- [ ] Изготовление и тестирование первого прототипа.

---

*Пока доступны: [BOM.ru.md](BOM.ru.md), [power_schematic.ru.md](power_schematic.ru.md), [weight_budget.ru.md](weight_budget.ru.md)*

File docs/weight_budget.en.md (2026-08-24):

# Component Weight Budget — Open-Humanoid-180

This document contains the up-to-date weight breakdown calculation for the robot by component category, reflecting the active power layout and the new actuator configuration (36 degrees of freedom).  
All weights are based on manufacturer data sheets, actual component measurements, or justified engineering estimates.

**Target Weight:** ~45–50 kg.  
**Calculated Weight:** ~51–52 kg (successfully minimized by switching to lightweight motors and compact silicone wiring).

---

## Motors

| Component | Qty | Unit Weight (kg) | Total (kg) | Notes |
| :--- | :---: | :---: | :---: | :--- |
| BLDC 6384 120KV (Heavy-duty, legs) | 6 | 0.650 | 3.90 | High-power belt/girdle zone (knees/thighs) |
| BLDC 5065 140KV (Medium-heavy, pelvis/torso) | 7 | 0.350 | 2.45 | High-torque actuators for large articulation joints |
| BLDC 5010 330KV (Base, arms/elbows) | 10 | 0.080 | 0.80 | Lightweight "pancake" form-factor with good torque density |
| BLDC 3205 110KV (Low-power, fingers/neck) | 13 | 0.035 | 0.455 | Miniature actuators for fine mechanics and joints |
| **Motors Total** | | | **7.605** |  |

---

## Motor Drivers

| Component | Qty | Unit Weight (kg) | Total (kg) | Notes |
| :--- | :---: | :---: | :---: | :--- |
| ODrive3.6 (Clone, legs) | 3 | 0.060 | 0.18 | Drives the 6384 motors (2 channels per board) |
| Hoverboard Driver Board (2 channels) | 9 | 0.100 | 0.90 | Drives the 5065 and 5010 motor groups |
| SimpleFOCMini (MS8313) | 13 | 0.010 | 0.13 | Tiny driver boards for the fingers and neck (3205) |
| **Drivers Total** | | | **1.21** |  |

---

## Sensors

| Component | Qty | Unit Weight (kg) | Total (kg) | Notes |
| :--- | :---: | :---: | :---: | :--- |
| MT6826S Magnetic Encoder | 36 | 0.002 | 0.072 | FOC feedback tracking modules for each motor |
| 9-Axis IMU BMI160 (+ QMC5883L) | 11 | 0.002 | 0.022 | Distributed localized telemetry modules |
| FSR402 Pressure Sensor (Fingers) | 10 | 0.001 | 0.010 | Thin-film resistors built into the hands |
| Foot Load Cell 100 kg | 4 | 0.010 | 0.040 | 2 individual weight load cells per foot |
| HX711 ADC Breakout Board | 2 | 0.002 | 0.004 | Localized digital conversion boards inside the feet |
| Dual HD USB Camera (OV4689) | 1 | 0.030 | 0.030 | AI vision system (paired with 3mm zero lenses) |
| **Sensors Total** | | | **0.178** |  |

---

## Computing & Logic Hubs

| Component | Qty | Unit Weight (kg) | Total (kg) | Notes |
| :--- | :---: | :---: | :---: | :--- |
| Laptop Motherboard (RTX 3080 / 32GB / 1TB) | 1 | 0.850 | 0.850 | Stripped down motherboard without chassis or display (VLM/YOLO/ROS2) |
| ESP32‑S3 N16R8 | 1 | 0.010 | 0.010 | Main low-level master controller |
| AT32F403A Bridge-MCU Board | 7 | 0.005 | 0.035 | Distributed localized CAN-bus hubs |
| CD74HC4067 Analog Multiplexer | 2 | 0.002 | 0.004 | Localized sensor data routing inside the hands |
| **Logic Total** | | | **0.899** |  |

---

## Battery & Power Routing Modules

| Component | Qty | Unit Weight (kg) | Total (kg) | Notes |
| :--- | :---: | :---: | :---: | :--- |
| Li‑NMC 3.7V 80.5Ah (SK Pouch Cell) | 7 | 0.900 | 6.300 | Primary 7S1P high-capacity power pack |
| JK‑B2A8S20P BMS (8S, 200A) | 1 | 0.200 | 0.200 | Battery block configuration management system |
| 1500W Step-Down DC-DC (28.8→19.5V) | 1 | 0.300 | 0.300 | Heavy duty converter feeding the RTX 3080 |
| 600W Step-Down DC-DC (28.8→5V) | 1 | 0.150 | 0.150 | Feeds the active LED matrix screen |
| 300W Step-Down DC-DC (28.8→5V) | 1 | 0.100 | 0.100 | Clean power line feeding logic buses & sensors |
| **Battery & Power Total** | | | **7.05** |  |

---

## Cables (Silicone + Industrial GOST)

*Weight is calculated based on the actual linear mass densities of multi-strand copper conductors and insulation layers.*

| Cable Specification / Gauge | Length | Weight per Meter (kg) | Total (kg) | Notes |
| :--- | :---: | :---: | :---: | :--- |
| PuGVng-LS 1×25 mm² Heavy-Gauge | 3 m | 0.290 | 0.870 | Primary high-current rail (Battery -> BMS -> Breaker -> Distro) |
| KGTP-XL 2×4 mm² Dual-Core | 10 m | 0.150 | 1.500 | Stationary high-amperage lines to ATO hub and ODrives |
| KGTP-XL 2×1.5 mm² Dual-Core | 10 m | 0.080 | 0.800 | Stationary lines feeding hoverboard drivers and DC-DC blocks |
| MKESHng(A)-LS 7×0.35 mm² Shielded | 20 m | 0.065 | 1.300 | Braided copper SPI buses (IMUs, encoders) + logic 5V power |
| MKESHng(A)-LS 5×0.35 mm² Shielded | 15 m | 0.050 | 0.750 | Braided copper CAN-bus hubs and HX711 foot data feeds |
| MKESHng(A)-LS 2×0.35 mm² Shielded | 5 m | 0.030 | 0.150 | Isolated limit switch lines, bumpers, and E-Stop loops |
| MGSHV 0.35 mm² Wire | 20 m | 0.006 | 0.120 | BMS cell balancing cables + localized tight enclosure wiring |
| Silicone 14 AWG (2.08 mm²) High-Flex | 50 m | 0.032 | 1.600 | Phase wiring for high-torque leg/hip BLDC motors (6384 & 5065) |
| Silicone 20 AWG (0.52 mm²) High-Flex | 50 m | 0.011 | 0.550 | Phase wiring for mid-tier arm BLDC actuators (10× 5010) |
| Silicone 26 AWG (0.13 mm²) High-Flex | 50 m | 0.004 | 0.200 | Ultra-fine phase wiring for finger BLDC servos and neck (13× 3205) |
| **Cables Total** | | | **7.84** |  |

---

## Connectors & Interconnect Terminals

| Component | Qty | Unit Weight (kg) | Total (kg) | Notes |
| :--- | :---: | :---: | :---: | :--- |
| 250A Power Distribution Block (12-term) | 2 | 0.150 | 0.300 | Solid brass-steel power busbars inside the torso |
| WAGO 221‑415 (5-wire lever) | 6 | 0.015 | 0.090 | Power distribution splits inside the arms and neck |
| WAGO 221‑413 (3-wire lever) | 2 | 0.010 | 0.020 | Power distribution splits inside the central torso cavity |
| QS8P‑S (Anti‑Spark Module) | 1 pair | 0.050 | 0.050 | Master battery manual disconnect coupling |
| XT90-S / XT90 Connector Pairs | 10 | 0.020 | 0.200 | Inter-chassis leg transit lines and ODrive links |
| XT60 Connector Pairs | 12 | 0.010 | 0.120 | Buck converter and hoverboard driver interface points |
| XT30 Connector Pairs | 5 | 0.005 | 0.025 | Interconnects feeding SimpleFOCMini modules |
| GX12 Panel Connectors (5-pin pairs) | 5 | 0.015 | 0.075 | Robust structural logic chassis disconnect nodes |
| JST‑XH 2.54 mm Interface Kit | 1 | 0.020 | 0.020 | Low-power sensor PCB connection array |
| **Connectors Total** | | | **0.90** |  |

---

## Fuse Hardware & System Protection

| Component | Qty | Unit Weight (kg) | Total (kg) | Notes |
| :--- | :---: | :---: | :---: | :--- |
| DC 2P Circuit Breaker 200A | 1 | 0.350 | 0.350 | Master heavy-duty dual-pole automatic breaker module |
| ATO Blade Fuse Block (10 Slots) | 1 | 0.050 | 0.050 | Secondary current management hub |
| ATO Blade Fuses (40A, 25A, 10A arrays) | 10 | 0.002 | 0.020 | Sacrificial current overcurrent fuse links |
| Inline Single Fuse Holders (w/ 80A Fuses) | 3 | 0.020 | 0.060 | Isolated protection runs dedicated to individual ODrives |
| **Protection Total** | | | **0.48** |  |

---

## Power Filters & Capacitors

| Component | Qty | Unit Weight (kg) | Total (kg) | Notes |
| :--- | :---: | :---: | :---: | :--- |
| Aluminum Electrolytic 50V 4700 μF | 6 | 0.015 | 0.090 | Bulk storage filter banks for the main high-power bus |
| Aluminum Electrolytic 25V 1000 μF | 10 | 0.005 | 0.050 | Smoothing output filters down the DC-DC converter lines |
| Ceramic Capacitors 50V 0.1 μF | 100 | 0.0005 | 0.050 | SMD bypass decoupling to counter HF driver noise |
| Hardware Resistors Array | 1 kit | 0.020 | 0.020 | General bleeding/pull-down array |
| **Filtering Total** | | | **0.21** |  |

---

## Display Matrix

| Component | Qty | Unit Weight (kg) | Total (kg) | Notes |
| :--- | :---: | :---: | :---: | :--- |
| P1.53 Flexible LED Panel (320×160 mm) | 1 | 0.200 | 0.200 | Dynamic expression matrix face panel |
| **Display Total** | | | **0.20** |  |

---

## Chassis Structure & Printing Materials

| Component | Qty | Unit Weight (kg) | Total (kg) | Notes |
| :--- | :---: | :---: | :---: | :--- |
| PETG Filament (Net Printed Part Weight) | — | — | 6.000 | External paneling, protection fairings, shroud layers |
| TPU A95 Flex-Filament (Net Printed Weight) | — | — | 1.000 | Vibration dampening gaskets, soft isolators, foot outsoles |
| PA12‑CF Carbon-Filled Nylon | — | — | 1.200 | Structural bearing seats, high-load arm shell matrices |
| Dual-Component Polyurethane/Silicone | — | — | 0.500 | Cast dampening areas and soft interface linings |
| Cast Aluminum (Skeleton Brackets / Mounts) | — | — | 3.500 | Core weight-bearing framework of hips, pelvis, and torso |
| Aluminum Tubing (Primary Chassis Spine) | — | — | 3.000 | Rigid extrusion long-runs feeding legs and spine lines |
| **Structure Total** | | | **15.20** |  |

---

## Hardware Fasteners & Spacers

| Component | Qty | Unit Weight (kg) | Total (kg) | Notes |
| :--- | :---: | :---: | :---: | :--- |
| Fasteners Matrix Set (M3, M4, M5, M6 arrays) | 1 kit | 0.500 | 0.500 | Total mass of high-tensile metal assembly screws |
| Solid Copper Connecting Links (Battery E805) | 8 | 0.015 | 0.120 | Custom custom cut bars out of electrical grade sheeting |
| M6 Flanged Tab Bolts and Matching Nuts | 16 | 0.005 | 0.080 | Secure compression fasteners linking cell tabs together |
| Heavy-Duty Ties, Shrink, and Electrical Wrap | 1 kit | 0.200 | 0.200 | General loom grouping and terminal isolation wraps |
| **Fasteners Total** | | | **0.90** |  |

---

## Strain Wave Reducers with PTK (36 Units)

_Mass calculation of joints incorporating steel intermediate rolling elements (rollers) and cast aluminum separator housings._

|Joint Application Node|Qty|Reduction Ratio|Unit Weight (kg)|Total (kg)|Notes|
|---|---|---|---|---|---|
|High-Torque Pivot (Legs/Knees) for 6384|6|1:100|0.500|3.00|Massive load rollers, maximized shell thickness|
|Mid-Torque Pivot (Pelvis/Shoulders) for 5065|7|1:65|0.300|2.10|Moderate shell profile, compact tracker|
|Standard Pivot (Elbows/Arms) for 5010|10|1:65 / 1:40|0.200|2.00|Specialized compact and slim profile housing lines|
|Miniature Pivot (Fingers/Neck) for 3205|13|1:40|0.080|1.04|Ultra-miniature custom wave-gear rolling sets|
|Reducers Total||||8.14||

---

## Consolidated Weight Summary Matrix

|Category Hub|Net Mass (kg)|Total Allocation %|
|---|---|---|
|Motors|7.605|14.8%|
|Drivers|1.210|2.4%|
|Sensors|0.178|0.3%|
|Logic Array|0.899|1.7%|
|Battery & Power Units|7.050|13.7%|
|Cable Runs Matrix|7.840|15.2%|
|Connectors|0.900|1.7%|
|Protection Devices|0.480|0.9%|
|Filtering Modules|0.210|0.4%|
|Expressions Screen|0.200|0.4%|
|Structural Material|15.200|29.5%|
|Fasteners Set|0.900|1.7%|
|Strain Wave Reducers (36 Units)|8.140|15.8%|
|TOTAL ASSEMBLY MASS|~50.81 kg|100%|

---

## Engineering Considerations for CAD Modeling Trace

- The Cable Mass Trap: Keep in mind that the cumulative weight of the cable tracks (7.84 kg) has officially surpassed the combined net weight of all 36 electric motors on the robot (7.605 kg). This is the unforgiving reality of scaling 1:1 humanoid electronics. Large silicone jackets and braided copper shielding inside the MKESH runs pack massive weight densities; slice away every redundant centimeter during CAD wire routing.
- Pelvic Center of Mass Offset: Given that the upper cavity is heavily saturated with the naked RTX 3080 board, the hefty 2P circuit breaker, distribution bars, and massive core torso gears, the true center of mass is heavily biased upward. The 6.3 kg pouch battery assembly must be mathematically mapped and locked inside a rigid, symmetrical matrix down the thigh structures to act as a counterweight if torso space proves entirely inadequate.
- Structural Mass Trimming Optimization: If the physical top-level assembly calculation breaks beyond the 52 kg threshold inside the CAD envelope, your main lever for shaving dead weight will be the separator housings of the arm gears (5010) and fingers (3205). Shifting those specific blocks from cast aluminum to high-grade carbon-fiber reinforced nylon (PA12-CF) 3D-prints will instantly shave roughly 1.5–2 kg of dead weight off the upper shoulder and hand assemblies.

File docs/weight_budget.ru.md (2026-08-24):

# Развесовка компонентов — Open-Humanoid-180

В этом документе приведён актуальный расчёт веса робота по категориям компонентов с учётом силовой схемы и новой конфигурации приводов (36 степеней свободы).  
Все веса основаны на спецификациях производителей, данных реальных компонентов или обоснованных инженерных расчётах.

**Целевой вес:** ~45–50 кг.  
**Расчётный вес:** ~51–52 кг (удалось снизить за счёт перехода на облегчённые моторы и компактную силиконовую проводку).

---

## Моторы

| Компонент | Кол‑во | Вес ед. (кг) | Итого (кг) | Примечания |
| :--- | :---: | :---: | :---: | :--- |
| BLDC 6384 120KV (Тяжёлые, ноги) | 6 | 0.650 | 3.90 | Силовой пояс (колени/бедра) |
| BLDC 5065 140KV (Средне-тяжёлые, таз/корпус) | 7 | 0.350 | 2.45 | Мясистые приводы крупных шарниров |
| BLDC 5010 330KV (Базовые, руки/локти) | 10 | 0.080 | 0.80 | Лёгкие «блинчики» с хорошим моментом |
| BLDC 3205 110KV (Слабые, пальцы/шея) | 13 | 0.035 | 0.455 | Миниатюрные приводы мелкой механики |
| **Моторы итого** | | | **7.605** |  |

---

## Драйверы моторов

| Компонент | Кол‑во | Вес ед. (кг) | Итого (кг) | Примечания |
| :--- | :---: | :---: | :---: | :--- |
| ODrive3.6 (клон, ноги) | 3 | 0.060 | 0.18 | Управляют 6384 (по 2 мотора на плату) |
| Плата гироскутера (2 канала) | 9 | 0.100 | 0.90 | Управляют моторами 5065 и 5010 |
| SimpleFOCMini (MS8313) | 13 | 0.010 | 0.13 | Мелкие драйверы для пальцев и шеи (3205) |
| **Драйверы итого** | | | **1.21** |  |

---

## Датчики

| Компонент | Кол‑во | Вес ед. (кг) | Итого (кг) | Примечания |
| :--- | :---: | :---: | :---: | :--- |
| Магнитный энкодер MT6826S | 36 | 0.002 | 0.072 | Модули обратной связи FOC на каждый мотор |
| 9‑осевой IMU BMI160 (+ QMC5883L) | 11 | 0.002 | 0.022 | Распределённые блины телеметрии |
| Датчик давления FSR402 (пальцы) | 10 | 0.001 | 0.010 | Тонкоплёночные в кистях рук |
| Тензодатчик стопы 100 кг | 4 | 0.010 | 0.040 | По 2 датчика на каждую стопу |
| АЦП HX711 | 2 | 0.002 | 0.004 | Локальные платы оцифровки прямо в стопах |
| Dual HD USB‑камера (OV4689) | 1 | 0.030 | 0.030 | Зрение ИИ (с 3mm zero линзами) |
| **Датчики итого** | | | **0.178** |  |

---

## Мозги и логика

| Компонент | Кол‑во | Вес ед. (кг) | Итого (кг) | Примечания |
| :--- | :---: | :---: | :---: | :--- |
| Ноутбук (RTX 3080 / 32GB / 1TB) | 1 | 0.850 | 0.850 | Голая материнка без корпуса и экрана (VLM/YOLO/ROS2) |
| ESP32‑S3 N16R8 | 1 | 0.010 | 0.010 | Главный контроллер нижней логики |
| Плата-мост AT32F403A | 7 | 0.005 | 0.035 | Распределённые CAN-хабы |
| Аналоговый мультиплексор CD74HC4067 | 2 | 0.002 | 0.004 | Локальный сбор сигналов FSR402 прямо в кистях |
| **Логика итого** | | | **0.899** |  |

---

## Батарея и питание

| Компонент | Кол‑во | Вес ед. (кг) | Итого (кг) | Примечания |
| :--- | :---: | :---: | :---: | :--- |
| Li‑NMC 3.7В 80.5Ач (pouch-ячейка SK) | 7 | 0.900 | 6.300 | Силовая сборка 7S1P |
| JK‑B2A8S20P BMS (8S, 200A) | 1 | 0.200 | 0.200 | Управление батарейным блоком |
| Понижайка 1500W (28.8→19.5В) | 1 | 0.300 | 0.300 | Питание ноута с RTX 3080 |
| Понижайка 600W (28.8→5В) | 1 | 0.150 | 0.150 | Питание LED-экрана |
| Понижайка 300W (28.8→5В) | 1 | 0.100 | 0.100 | Питание хаба логики и датчиков |
| **Батарея и питание итого** | | | **7.05** |  |

---

## Кабели (Силикон + ГОСТ)

*Вес рассчитывается на основе реальной погонной массы медных многожильных проводников и типов изоляции.*

| Марка / Тип кабеля | Длина | Вес на метр (кг) | Итого (кг) | Примечания |
| :--- | :---: | :---: | :---: | :--- |
| ПуГВнг-LS 1×25 мм² | 3 м | 0.290 | 0.870 | Силовая магистраль (АКБ -> BMS -> Автомат -> ГРБ) |
| КГТП-ХЛ 2×4 мм² | 10 м | 0.150 | 1.500 | Стационарное питание хаба ATO и плат ODrive |
| КГТП-ХЛ 2×1.5 мм² | 10 м | 0.080 | 0.800 | Стационарное питание плат гироскутеров и DC-DC |
| МКЭШнг(А)-LS 7×0.35 мм² | 20 м | 0.065 | 1.300 | Экранированные шины SPI (IMU, энкодеры) + питание 5В |
| МКЭШнг(А)-LS 5×0.35 мм² | 15 м | 0.050 | 0.750 | Экранированные CAN-шины хабов и выходы HX711 |
| МКЭШнг(А)-LS 2×0.35 мм² | 5 м | 0.030 | 0.150 | Экранированные трассы концевиков и кнопки E-Stop |
| МГШВ 0.35 мм² | 20 м | 0.006 | 0.120 | Балансировочные хвосты BMS и внутрикорпусной монтаж |
| Силикон 14 AWG (2.08 мм²) | 50 м | 0.032 | 1.600 | Фазы тяжелых моторов ног и таза (6384 и 5065) |
| Силикон 20 AWG (0.52 мм²) | 50 м | 0.011 | 0.550 | Фазы средних моторов рук (10 шт 5010) |
| Силикон 26 AWG (0.13 мм²) | 50 м | 0.004 | 0.200 | Фазы мелких моторов пальцев и шеи (13 шт 3205) |
| **Кабели итого** | | | **7.84** |  |

---

## Разъёмы и распределители

| Компонент | Кол‑во | Вес ед. (кг) | Итого (кг) | Примечания |
| :--- | :---: | :---: | :---: | :--- |
| Распределительный блок 250А (11 выводов) | 2 | 0.150 | 0.300 | Латунно-стальные шины в торсе |
| WAGO 221‑415 (5 контактов) | 6 | 0.015 | 0.090 | Силовые разветвители рук/шеи |
| WAGO 221‑413 (3 контакта) | 2 | 0.010 | 0.020 | Силовые разветвители торса |
| QS8P‑S (Anti‑Spark) | 1 пара | 0.050 | 0.050 | Главный силовой разъем АКБ |
| XT90-S / XT90 (пары) | 10 | 0.020 | 0.200 | Силовой транзит ног и ODrive |
| XT60 (пары) | 12 | 0.010 | 0.120 | Подключения понижаек и гиро-плат |
| XT30 (пары) | 5 | 0.005 | 0.025 | Линии SimpleFOCMini |
| GX12 (5‑pin пары) | 5 | 0.015 | 0.075 | Сигнальные межблочные стыки |
| JST‑XH 2.54 мм (набор) | 1 | 0.020 | 0.020 | Коммутация на платах датчиков |
| **Разъёмы итого** | | | **0.90** |  |

---

## Предохранители и защита

| Компонент | Кол‑во | Вес ед. (кг) | Итого (кг) | Примечания |
| :--- | :---: | :---: | :---: | :--- |
| Автомат DC 200А 2P | 1 | 0.350 | 0.350 | Двухполюсный силовой автомат защиты |
| Хаб предохранителей ATO (10 гнёзд) | 1 | 0.050 | 0.050 | Вторичное распределение |
| Предохранители ATO (40А, 25А, 10А) | 10 | 0.002 | 0.020 | Защитные плавкие вставки |
| Одиночные держатели с предами 80А | 3 | 0.020 | 0.060 | Выделенная защита плат ODrive3.6 |
| **Защита итого** | | | **0.48** |  |

---

## Конденсаторы и фильтрация

| Компонент | Кол‑во | Вес ед. (кг) | Итого (кг) | Примечания |
| :--- | :---: | :---: | :---: | :--- |
| Алюминиевый электролит 50V 4700 мкФ | 6 | 0.015 | 0.090 | Буферы силовой шины |
| Алюминиевый электролит 25V 1000 мкФ | 10 | 0.005 | 0.050 | Фильтры выходов DC-DC |
| Керамический конденсатор 50V 0.1 мкФ | 100 | 0.0005 | 0.050 | SMD-фильтрация ВЧ-помех |
| Разное (резисторы, мелочевка) | 1 набор | 0.020 | 0.020 |  |
| **Фильтрация итого** | | | **0.21** |  |

---

## Экран

| Компонент | Кол‑во | Вес ед. (кг) | Итого (кг) | Примечания |
| :--- | :---: | :---: | :---: | :--- |
| Гибкий LED P1.53 320×160 мм | 1 | 0.200 | 0.200 | Матрица лица робота |
| **Экран итого** | | | **0.20** |  |

---

## Конструкционные материалы и печать

| Компонент | Кол‑во | Вес ед. (кг) | Итого (кг) | Примечания |
| :--- | :---: | :---: | :---: | :--- |
| PETG-пластик (чистый вес деталей) | — | — | 6.000 | Внешний обвес, защитные кожухи |
| TPU A95-флекс (чистый вес деталей) | — | — | 1.000 | Мягкие проставки, демпферы, подошвы стоп |
| PA12‑CF угленаполненный нейлон | — | — | 1.200 | Обоймы подшипников, силовые узлы рук |
| Двухкомпонентный полиуретан/силикон | — | — | 0.500 | Заливка мягких зон |
| Литьё алюминия (кронштейны, скелет) | — | — | 3.500 | Основные несущие элементы бедер, таза и торса |
| Алюминиевые трубы (силовой каркас) | — | — | 3.000 | Длинномеры скелета ног и позвоночника |
| **Конструкция итого** | | | **15.20** |  |

---

## Крепёж и метизы

| Компонент | Кол‑во | Вес ед. (кг) | Итого (кг) | Примечания |
| :--- | :---: | :---: | :---: | :--- |
| Болты, гайки, винты (М3, М4, М5, М6) | 1 набор | 0.500 | 0.500 | Весь силовой металлический крепеж |
| Медные шины-перемычки для АКБ E805 | 8 | 0.015 | 0.120 | Нарезка из листовой электротехнической меди |
| Гайки и болты фланцевые М6 (табы) | 16 | 0.005 | 0.080 | Болтовое зажатие ячеек |
| Термоусадка, стяжки, изолента | 1 набор | 0.200 | 0.200 | Расходники укладки жгутов |
| **Крепёж итого** | | | **0.90** |  |

---

## Редукторы волновые с ПТК (36 шт)

*Расчёт массы узлов с учётом стальных промежуточных тел качения (роликов) и литых алюминиевых корпусов сепараторов.*

| Назначение привода | Кол‑во | Передаточное число | Вес ед. (кг) | Итого (кг) | Примечания |
| :--- | :---: | :---: | :---: | :---: | :--- |
| Мощные шарниры (ноги/колени) под 6384 | 6 | 1:100 | 0.500 | 3.00 | Самые крупные ролики, максимальная нагрузка |
| Средние шарниры (таз/плечи) под 5065 | 7 | 1:65 | 0.300 | 2.10 | Умеренный габарит сепаратора |
| Базовые шарниры (локти/руки) под 5010 | 10 | 1:65 / 1:40 | 0.200 | 2.00 | Компактные и облегченные редукторы |
| Мелкие шарниры (пальцы/шея) под 3205 | 13 | 1:40 | 0.080 | 1.04 | Миниатюрные ПТК-редукторы |
| **Редукторы итого** | | | | **8.14** |  |

---

## Сводная таблица веса

| Категория | Вес (кг) | Доля (%) |
| :--- | :---: | :---: |
| Моторы | 7.605 | 14.8% |
| Драйверы | 1.210 | 2.4% |
| Датчики | 0.178 | 0.3% |
| Логика | 0.899 | 1.7% |
| Батарея и питание | 7.050 | 13.7% |
| Кабели | 7.840 | 15.2% |
| Разъёмы | 0.900 | 1.7% |
| Защита | 0.480 | 0.9% |
| Фильтрация | 0.210 | 0.4% |
| Экран | 0.200 | 0.4% |
| Конструкция | 15.200 | 29.5% |
| Крепёж | 0.900 | 1.7% |
| Редукторы волновые с ПТК (36 шт) | 8.140 | 15.8% |
| **ИТОГО** | **~50.81 кг** | **100%** |

---

## Примечания и допущения для проектирования в CAD

- **Кабельная ловушка:** Обрати внимание, что вес кабельных трасс (**7.84 кг**) превысил общий вес всех моторов робота (**7.605 кг**). Это суровая реальность гуманоидов масштаба 1:1. Тонны силикона и медные экраны МКЭШ весят очень много, поэтому при трассировке в CAD вырезай каждый лишний сантиметр длины.
- **Развесовка таза:** Из-за того, что в торс забиты голая плата ноута с RTX 3080, тяжелый 2P автомат, распределительные блоки и крупные редукторы корпуса, центр масс смещен вверх. Сборка ячеек питания (6.3 кг) в качестве противовеса должна проектироваться с возможностью жесткого симметричного закрепления в бедрах, если объёма таза физически не хватит.

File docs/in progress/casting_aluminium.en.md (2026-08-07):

# Backyard Aluminium Casting — Open-Humanoid-180

> **Status:** work in progress.
>
> Step‑by‑step guide for casting aluminium parts (reducer housings, brackets) in a homemade furnace.

## Planned Content

- Coal‑fired furnace (forge) setup using the existing construction.
- Melting aluminium scrap (profiles, cans, cast parts).
- Degassing the melt: using salt and soda to remove oxides.
- Sand mould making (sand type, binder, ramming technique).
- Pouring and part extraction.
- Finishing on a lathe / milling machine (turning, drilling).

## Status

- [x] Test melt – successful.
- [x] Degassing agent composition defined (salt + soda).
- [ ] Sand mould development for complex geometries (reducers).
- [ ] First batch of housings to be cast.

---

*Available now: [BOM.en.md](BOM.en.md), [power_schematic.en.md](power_schematic.en.md), [weight_budget.en.md](weight_budget.en.md)*

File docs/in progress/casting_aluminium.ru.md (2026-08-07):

# Литьё алюминия в домашних условиях — Open-Humanoid-180

> **Статус:** в разработке.
>
> Пошаговое руководство по литью алюминиевых деталей (корпусов редукторов, кронштейнов) в самодельной печи.

## Планируемое содержание

- Устройство угольного горна (печи) на основе имеющейся конструкции.
- Плавка алюминиевого лома (профили, банки, литьё).
- Раскисление расплава: использование соли и соды для удаления оксидов.
- Изготовление песчаных форм (тип песка, связующее, уплотнение).
- Заливка и извлечение отливок.
- Финишная обработка на токарном/фрезерном станке (подрезка, сверление).

## Статус

- [x] Тестовая плавка алюминия — успешно.
- [x] Определён состав раскислителя (соль + сода).
- [ ] Отработка песчаных форм для сложных геометрий (редукторы).
- [ ] Изготовление первой партии корпусов.

---

*Пока доступны: [BOM.ru.md](BOM.ru.md), [power_schematic.ru.md](power_schematic.ru.md), [weight_budget.ru.md](weight_budget.ru.md)*

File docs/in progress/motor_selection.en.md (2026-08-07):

# Actuator Calculations — Open-Humanoid-180

> **Status:** work in progress.
>
> This document will contain the complete actuator system calculations for the robot.

## Planned Content

- KV selection for each motor type (6384, 5065, 3205) with justification.
- Torque calculations for each joint, based on the robot's estimated weight (~50 kg).
- Required reduction ratios for high‑torque (1:100), medium (1:65), and base (1:40) joints.
- Current margin verification for selected drivers (ODrive, hoverboard ESCs, SimpleFOCMini).
- Peak and continuous load estimates for walking gait.

## When It Will Be Completed

This document will be finalized after:
1. Full CAD model of the robot is built.
2. Kinematics and dynamics calculations are completed in Gazebo or MATLAB.
3. First joint prototype is tested on a bench.

---

*Available now: [BOM.en.md](BOM.en.md), [power_schematic.en.md](power_schematic.en.md), [weight_budget.en.md](weight_budget.en.md)*

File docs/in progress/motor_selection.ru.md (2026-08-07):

# Расчёт приводов — Open-Humanoid-180

> **Статус:** в разработке.
>
> Этот документ будет содержать полный расчёт приводной системы робота.

## Планируемое содержание

- Выбор KV для каждого типа мотора (6384, 5065, 3205) с обоснованием.
- Расчёт моментов на каждом суставе с учётом веса робота (~50 кг).
- Определение требуемой редукции для мощных (1:100), средних (1:65) и базовых (1:40) суставов.
- Проверка запаса по току для выбранных драйверов (ODrive, платы гироскутеров, SimpleFOCMini).
- Оценка пиковых и продолжительных нагрузок в режиме ходьбы.

## Когда будет заполнен

Документ будет завершён после:
1. Построения полной CAD-модели робота.
2. Проведения расчётов кинематики и динамики в Gazebo или MATLAB.
3. Тестирования первого прототипа сустава на стенде.

---

*Пока доступны: [BOM.ru.md](BOM.ru.md), [power_schematic.ru.md](power_schematic.ru.md), [weight_budget.ru.md](weight_budget.ru.md)*

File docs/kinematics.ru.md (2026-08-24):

# Кинематическая схема Open-Humanoid-180

## Общие параметры
- **Рост:** 180 см
- **Вес:** ~60 кг
- **Общее число степеней свободы (DoF):** 36
- **Число приводов:** 36 (каждый DoF обслуживается отдельным BLDC-мотором)
- **Типы моторов:**
  - Мощные (6384 120KV) – 6 шт.
  - Средние (5065 140KV) – 7 шт.
  - Базовые (5010 360KV) – 10 шт.
  - Слабые (3205 110KV) – 13 шт.
- **Редукторы:** волновые (или циклоидальные) с передаточными числами:
  - 1:100(1:10+1:10) – для мощных
  - 1:64(1:8+1:8) – для средних и базовых(в тазу)
  - 1:42(1:7+1:6) – для слабых и базовых(в плечах, локтях и кистях)

---

## Распределение осей по суставам

### Нижние конечности – 8 осей (6 мощных + 2 базовых)
| Сустав | Количество осей | Тип мотора |
|---|---|---|
| Тазобедренный левый | 3 (сгибание-разгибание, отведение-приведение, вращение) | 2 мощных + 1 базовый |
| Тазобедренный правый | 3 (сгибание-разгибание, отведение-приведение, вращение) | 2 мощных + 1 базовый |
| Колено левое | 1 (сгибание-разгибание) | 1 мощный |
| Колено правое | 1 (сгибание-разгибание) | 1 мощный |

> **Примечание:** стопы выполнены в виде пассивных скруглённых цилиндров без подвижных суставов.

---

### Корпус – 4 оси (1 средний + 3 слабых)
| Сустав | Количество осей | Тип мотора |
| --- | --- | --- |
| Поясничный отдел (живот) | 1 (наклон вперёд-назад) | 1 средний  |
| Шейный отдел | 3 (наклон, поворот, наклон вбок) | 3 слабых |

---

### Верхние конечности – 24 оси (6 средних + 8 базовых+ 10 слабых)
| Сустав | Количество осей | Тип мотора |
| --- | --- | --- |
| Плечо левое | 3 (подъём, отведение, вращение) | 2 средних и 1 базовый |
| Плечо правое | 3 (подъём, отведение, вращение) | 2 средних и 1 базовый |
| Локоть левый | 2 (сгибание-разгибание + вращение предплечья) | 1 средних и 1 базовый |
| Локоть правый | 2 (сгибание-разгибание + вращение предплечья) | 1 средних и 1 базовый |
| Кисть левая | 2 (сгибание-разгибание, отведение-приведение) | 2 базовый |
| Кисть правая | 2 (сгибание-разгибание, отведение-приведение) | 2 базовый |
| Пальцы левой руки (5 шт.)  | по 1 оси на палец (сгибание) | 5 слабых |
| Пальцы правой руки (5 шт.) | по 1 оси на палец (сгибание) | 5 слабых |

> **Примечание:** каждый палец имеет один привод, что обеспечивает базовый захват, но не воспроизводит полную анатомическую подвижность.

---

## Сводная таблица по типам моторов

| Тип | Количество | Где используются |
| --- | --- | --- |
| 6384 120KV (мощный) | 6 | Таз (4) + колени (2) |
| 5065 140KV (средний) | 7 | Живот (1), плечи (4), локти (2) |
| 5010 360KV (базовый) | 10 | Таз (2), плечи (2), локти (2), кисти(4) |
| 3205 110KV <br>(слабый) | 13 | Шея (3) + пальцы (10) |

---

## Управление приводами
- **Мощные, средние и базовые моторы** управляются через контроллеры ODrive 3.6(мощьные) или платы гироскутеров(средние и базовые) с энкодерами MT6826S.
- **Слабые моторы** – через SimpleFOCMini на базе AT32F403ACGU7 с энкодерами MT6826s.
- **Центральный процессор:** ESP32-S3 (как шлюз) + ноутбук с RTX 3080 для высокоуровневых вычислений.

---

## Питание
- Аккумулятор 10S Li‑NMC, BMS на 200А.
- Распределение питания через DC‑DC преобразователи и защитные автоматы.

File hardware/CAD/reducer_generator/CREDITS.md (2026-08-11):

# Благодарности за CAD-инструменты

В этой папке находятся скрипты для генерации профиля волнового редуктора с промежуточными телами качения (ПТК).  
Исходные коды взяты из открытых репозиториев и адаптированы для нужд проекта Open-Humanoid-180.

## Авторы и лицензии

| Файл | Автор | Оригинальный источник | Лицензия |
| :--- | :--- | :--- | :--- |
| **`reducer_generator.py`** | [TrashRobotics](https://www.youtube.com/@trashrobotics) | [Codeberg](https://codeberg.org/TrashRobotics/BallsWaveGearingGenerator) | GPLv2 |
| **`reducer_generator_gui.py`** | [Jkl88](https://github.com/Jkl88) | [GitHub](https://github.com/Jkl88/BallsWaveGearingGenerator) | GPLv2 (производная от GPLv2) |

---

**Примечание:**  
- Оригинальный скрипт (`reducer_generator.py`) создан TrashRobotics и распространяется под GPLv2.  
- Версия с графическим интерфейсом (`reducer_generator_gui.py`) является модификацией, выполненной Jkl88. Несмотря на то, что в его репозитории указана лицензия Unlicense, юридически он обязан распространять производную работу под GPLv2, поэтому мы указываем именно её.  
- Оба файла используются в проекте Open-Humanoid-180, который распространяется под GPLv3, что совместимо с GPLv2.

---

*Если вы являетесь автором этих скриптов и считаете, что мы указали что-то неверно, пожалуйста, свяжитесь с нами.*

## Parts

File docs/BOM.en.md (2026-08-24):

# Bill of Materials (BOM) — Open-Humanoid-180

*Prices are approximate as of July–August 2026, including shipping (when buying the required quantity in one lot). All amounts are in Russian Rubles (RUB).*

---

## Motors & Actuators

| Component | Qty | Unit Price (RUB) | Total (RUB) | Link |
| --- | --- | --- | --- | --- |
| BLDC 6384 120KV | 6 | 4 000 | 24 000 | [Ozon](https://www.ozon.ru/product/elektricheskiy-balansirovochnyy-samokat-skeytbord-6384-120kv-bez-datchika-3607953100/) |
| BLDC 5065 140KV | 7 | 2 700 | 18 900 | [Ozon](https://www.ozon.ru/product/diy-n5065-140kv-bldc-besshchetochnyy-dvigatel-dlya-elektroskutera-bezdatchikovyy-1986965132/) |
| BLDC 5010 360KV | 10  | 1 000 | 10 000 | [Ozon](https://www.ozon.ru/product/besshchetochnye-dvigateli-5010-360-kv-s-vysokim-krutyashchim-momentom-dlya-razlichnyh-4198584996/) |
| BLDC 3205 110KV | 13  | 360 | 4 680 | [AliExpress](https://aliexpress.ru/item/1005010807047447.html) |
| Needle roller 4×6 mm G3 | 300 | 3.5 | 1 050 | [Rusmet](https://www.tdrusmet.ru/roliki/4x6mm-g3-rolik?sort=p.price&order=ASC&limit=100) |
| Needle roller 8×8 mm G3 | 300 | 5.8 | 1 740 | [Rusmet](https://www.tdrusmet.ru/8x8mm-g3-rolik) |

---

## Motor Drivers

| Component | Qty | Unit Price (RUB) | Total (RUB) | Link |
|---|-----|---|---|---|
| ODrive 3.6 (clone) | 3 | 3 400 | 10 200 | [Ozon](https://www.ozon.ru/product/foc-bldc-dual-motor-controller-xdrive-xdrive3-6-apgreyd-kit-56v-dlya-servo-vysokotochnyy-na-5046874017/) |
| Hoverboard mainboard (2‑ch)| 9  | 1 500 | 13 500 | [Avito](https://www.avito.ru/ekaterinburg/sport_i_otdyh/platy_upravleniya_giroskutera_42v_8164713218) (used) |
| SimpleFOCMini (MS8313) | 13  | 185 (255 for single) | 2 615 | [AliExpress](https://aliexpress.ru/item/1005008486050546.html) (lot of 10 + 1 pc) |

---

## Sensors

| Component | Qty | Unit Price (RUB) | Total (RUB) | Link |
|---|-----|---|---|---|
| Magnetic encoder MT6826S  | 36  | 280 | 10 080 | [AliExpress](https://aliexpress.ru/item/1005008498235469.html) |
| Force sensor FSR402 | 10  | 180 | 1 800 | [AliExpress](https://aliexpress.ru/item/4001062799587.html) |
| 9‑axis IMU ICM-20948 | 1 | 660 | 660 | [Ozon](https://www.ozon.ru/product/k2-20948-malomoshchnyy-9-osevoy-mems-datchik-otslezhivaniya-dvizheniya-ozy2-4015404965/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) |
| 6‑axis IMU BMI160 | 20  | 90 | 1 800 | [Ozon](https://www.ozon.ru/product/10-komplektov-bmi160-gy-bmi160-6dof-6-osevoy-modul-datchika-akselerometra-1726319765/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) (lot of 10) |
| Load cell 100 kg XNQJALYCY| 4 | 230 | 920 | [AliExpress](https://aliexpress.ru/item/1005006769729312.html) (lot of 4) |
| ADC HX711 | 4 | 42 (lot of 10: 420) | 168 | [AliExpress](https://aliexpress.ru/item/1005009105560158.html) (lot of 10) |
| Dual HD USB Camera (OV4689)| 1  | 6 500 | 6 500 | [AliExpress](https://aliexpress.ru/item/1005010126423504.html) |

---

## Brains & Logic

| Component | Qty | Unit Price (RUB) | Total (RUB) | Link |
|---|-----|---|---|---|
| Laptop Lenovo L7 / R9 / RTX 3080 / 32GB / 1TB (used) | 1 | 86 000 | 86 000 | [Avito](https://www.avito.ru/moskva/noutbuki/noutbuk_lenovo_l7_r9_rtx_3080_32gb_1tb_8203230225) |
| ESP32‑S3 N16R8 | 1 | 410 | 410 | [AliExpress](https://aliexpress.ru/item/1005009303526431.html) |
| GPIO expansion board for ESP32‑S3 | 1 | 355 | 355 | [AliExpress](https://aliexpress.ru/item/1005009799215827.html) |
| AT32F403ACGU7 | 7 | 340 | 2 380 | [AliExpress](https://aliexpress.ru/item/1005004842376803.html) |
| STM32F103C8T6 | 10  | 150 | 1 500 | [AliExpress](https://aliexpress.ru/item/1005001892019439.html?sku_id=12000018034505390) |
| CAN transceiver SN65HVD230 | 20  | 100 | 2 000 | [AliExpress](https://aliexpress.ru/item/1005008710123474.html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) |
| Analog multiplexer CD74HC4067 | 2 | 50 | 100 | [AliExpress](https://aliexpress.ru/item/1005005507548696.html) |

---

## Battery & Power

| Component | Qty | Unit Price (RUB) | Total (RUB) | Link |
|---|-----|---|---|---|
| Li‑NMC SK 3.7 V 80.5 Ah cell | 10  | 3 000 | 30 000 | [Avito](https://www.avito.ru/sankt-peterburg/orgtehnika_i_rashodniki/litiy-ionnye_yacheyki_li-nmc_sk_37v_805ah_8259027903) |
| JK‑B2A24S20P Smart BMS (8S-24S, 200 A) | 1 | 7 000 | 7 000 | [AliExpress](https://aliexpress.ru/item/1005011930339277.html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) |
| Buck converter 1 500 W (28.8→19.5 V) | 1 | 1 500 | 1 500 | [AliExpress](https://aliexpress.ru/item/1005009348542795.html) |
| Buck converter 600 W (28.8→5 V) | 3 | 500 | 1 500 | [Ozon](https://www.ozon.ru/product/dc-dc-ponizhayushchiy-preobrazovatel-600-vt-stabilizator-2635865398/) |

---

## Wires & Cables

| Component | Qty | Unit Price (RUB/m) | Total (RUB) | Link |
|---|-----|---|---|---|
| KOG1-T 1×25 mm² | 3 m | 200 | 600 | [N-Kabel](https://nn.n-kabel.ru/position/kog1_t_1h25/) |
| KGTP‑HL 2×4 mm² | 10 m| 121.66 | 1 217 | [Cable‑ES](https://cable-es.ru/catalog/kgtp-hl/kgtp-hl-2h4/) |
| KGTP‑HL 2×1.5 mm² | 10 m| 49.73 | 497 | [Cable‑ES](https://cable-es.ru/catalog/kgtp-hl/kgtp-hl-2h1-5/) |
| MKEShng(A)‑LS 7×0.35 mm² | 10 m| 76.42 | 765 | [Cable‑ES](https://cable-es.ru/catalog/mkeshng-ls/mkeshng-a-ls-7h0-35/) |
| MKEShng(A)‑LS 5×0.35 mm² | 10 m| 60.24 | 603 | [Cable‑ES](https://cable-es.ru/catalog/mkeshng-ls/mkeshng-a-ls-5h0-35/) |
| MKEShng(A)‑LS 2×0.35 mm² | 5 m | 34.18 | 171 | [Cable‑ES](https://cable-es.ru/catalog/mkeshng-ls/mkeshng-a-ls-2h0-35/) |
| MGShV 0.35 mm² | 20 m| 7.12 | 142 | [Cable‑ES](https://cable-es.ru/catalog/mgshv/mgshv-0-35/) |
| 14 AWG silicone wire | 50 m| 75 | 3 750 | [Ozon](https://www.ozon.ru/product/silikonovyy-elektricheskiy-provod-awg-14-2-08mm-1-1-metr-chernyy-krasnyy-769143306/) |
| 20 AWG silicone wire | 50 m| 30 | 1 500 | [Ozon](https://www.ozon.ru/product/20awg-5-tsvetov-po-10-metrov-nabor-silikonovyh-mnogozhilnyh-provodov-3466223449/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) |
| 26 AWG silicone wire | 50 m| 16 | 800 | [Ozon](https://www.ozon.ru/product/nabor-provodov-dlya-payki-2375724297/) |
| 30 AWG silicone wire | 100m| 10.5 | 1 050 | [Ozon](https://www.ozon.ru/product/nabor-silikonovyh-mnogozhilnyh-provodov-30awg-5-tsvetov-po-20-metrov-1630156271/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) |

---

## Connectors, Terminals, Distributors

| Component | Qty  | Unit Price (RUB) | Total (RUB) | Link |
|---|---|---|---|---|
| Distribution block 250 A (11 terminals)| 2 | 788 | 1 576 | [Ozon](https://www.ozon.ru/product/blok-raspredelitelnyy-kbr-rbd-250-250a-12-prisoedineniy-dekron-4045680559/) |
| WAGO 221‑415 (5‑way) | 6 | 44 | 264 | [Ozon](https://www.ozon.ru/product/klemma-wago-221-415-5-provodnaya-dlya-soedineniya-provodov-10-sht-2008848825/) |
| WAGO 221‑413 (3‑way) | 2 | 39 | 78 | [Ozon](https://www.ozon.ru/product/klemma-wago-221-413-3-h-provodnaya-dlya-soedineniya-provodov-vago-10-sht-2008848822/) |
| QS8P‑S (Anti‑Spark) | 1 pair | 682 | 682 | [Ozon](https://www.ozon.ru/product/razem-dlya-modifikatsii-akkumulyatora-elektromobilya-qs8p-l-vysokotochnyy-razem-dlya-zashchity-3302358304/) |
| XT90 (5 pairs per lot) | 6 pairs | 118.4 | 710 | [Ozon](https://www.ozon.ru/product/konnektor-silovoy-xt90-m-f-razem-papa-mama-5-par-amass-1410065195/) |
| XT60 (5 pairs per lot) | 12 pairs | 30.6 | 367 | [AliExpress](https://aliexpress.ru/item/33061763696.html) |
| XT30 (5 pairs per lot) | 5 pairs  | 30.2 | 151 | [AliExpress](https://aliexpress.ru/item/33061763696.html) |
| XT60h (optional, 5 pairs) | — | 61.8 | — | [AliExpress](https://aliexpress.ru/item/1005007299555986.html) |
| GX12 (5‑pin) | 5 pairs  | ~150 | 750 | *(generic)* |
| JST‑XH 2.54 mm | 1 set | ~300 | 300 | *(generic)* |

---

## Fuses & Protection

| Component | Qty | Unit Price (RUB) | Total (RUB) | Link |
| --- | --- | --- | --- | --- |
| DC circuit breaker 200 A | 1 | 2 400 | 2 400 | [AliExpress](https://aliexpress.ru/item/1005005566503592.html) |
| Fuse holder hub (10 slots) | 1 | 640 | 640 | [AliExpress](https://aliexpress.ru/item/1005005781273635.html) |
| ATO fuse 40 A | 7 | 1.2 (lot of 30)  | 36 (lot) | [Ozon](https://www.ozon.ru/product/predohranitel-avtomobilnyy-30-sht-art-40a-4633025301/) |
| ATO fuse 25 A | 2 | 2.63 (lot of 30) | 79 (lot) | [Ozon](https://www.ozon.ru/product/predohranitel-avtomobilnyy-30-sht-art-25a-4633034058/) |
| ATO fuse 10 A | 1 | 1.96 (lot of 30) | 59 (lot) | [Ozon](https://www.ozon.ru/product/predohranitel-avtomobilnyy-30-sht-art-10a-4633021334/) |
| Single holder + 80 A fuse (for ODrive) | 3 | 163 | 489 | [AliExpress](https://aliexpress.ru/item/1005005850402237.html) |
| Ideal diode module 80V 50A | 1 | 600 | 600 | [Ozon](https://www.ozon.ru/product/modul-idealnogo-dioda-s-vysokim-tokom-80v-50a-s-klemmoy-4840017570/?sh=HZL6ZeYCXw) |

---

## Capacitors & Filtering

| Component | Qty | Unit Price (RUB) | Total (RUB) | Link |
|---|-----|---|---|---|
| Aluminium capacitor 63 V 4 700 µF | 10  | 92.5 | 925 | [AliExpress](https://aliexpress.ru/item/1005005776158492.html?sku_id=12000034312209898) (lot of 2) |
| Aluminium capacitor 35 V 2 200 µF | 15  | 26.8 | 401 | [AliExpress](https://aliexpress.ru/item/1005003663338815.html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) (lot of 5) |
| Ceramic capacitor 50 V 0.1 µF (104) | 100 | 1.01 | 101 | [AliExpress](https://aliexpress.ru/item/4000368078609.html) (lot of 100) |
| Resistor kit VKTECH 300 pcs | 1 | 320 | 320 | [AliExpress](https://aliexpress.ru/item/1005009483805314.html) |
| LC filter 50V 4A | 1 | 150 | 150 | [Ozon](https://www.ozon.ru/product/plata-filtra-pitaniya-postoyannogo-toka-podavlenie-pomeh-dlya-istochnika-pitaniya-0-50v-2a-3a-4a-3280420183/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) |
| LC filter 50V 20A | 1 | 500 | 500 | [Ozon](https://www.ozon.ru/product/avtomobilnyy-emi-filtr-dlya-audiosistemy-20-a-3287207466/?sh=HZL6ZV56Kg) |

---

## Display & Visualization

| Component | Qty | Unit Price (RUB) | Total (RUB) | Link |
|---|-----|---|---|---|
| Flexible LED P1.53 320×160 mm (209×104) | 1 | 5 500 | 5 500 | [AliExpress](https://aliexpress.ru/item/1005008740646437.html) |

---

## Plastics & Materials

| Component | Qty | Unit Price (RUB) | Total (RUB) | Link |
|---|-----|---|---|---|
| PETG (Hexalit, 5 kg × 2) | 10 kg | 600/kg | 6 000 | [Ozon](https://www.ozon.ru/product/petg-chernyy-plastik-dlya-3d-pechati-geksalit-1-75mm-5-motkov-filamenta-po-1-kg-2425802879/) |
| TPU A95 (Elegoo) | 2 kg  | 1 160/kg | 2 320 | [AliExpress](https://aliexpress.ru/item/1005007342881359.html) |
| PETG GF15 | 3 kg  | 1 100/kg | 3 300 | [Ozon](https://www.ozon.ru/product/petg-gf-plastik-dlya-3d-printera-chernyy-armirovannyy-steklovoloknom-300-13-mkm-15-4355981121/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) |
| PETG CFF M405 | 1 kg  | 1 900/kg | 1 900 | [Ozon](https://www.ozon.ru/product/petg-plastik-u3-cff-m-405-dlya-3d-pechati-inzhenernyy-professionalnyy-chernyy-1kg-764551726/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) |
| PETG CF15 | 3 kg  | 1 550/kg | 4 650 | [Ozon](https://www.ozon.ru/product/prizm-petg-cf-carbon-fiber-plastik-1-75-mm-1-kg-chernyy-3613193935/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) |
| Two‑component platinum‑cure silicone | 10 kg | ~1 500/kg | 15 000 | *(generic)* |
| Electrocorundum 25A M2.5 F2500 | 4 kg  | 850/kg | 3 400 | [Ozon](https://www.ozon.ru/product/sk-mineral-abraziv-dlya-peskostruynyh-apparatov-1-l-1000-g-1-sht-1415226313/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) |

---

## Fasteners & Miscellaneous

| Component | Qty | Estimated Price (RUB) |
|---|-----|---|
| Unaccounted | — | 5 000 |
| TML 10‑6 terminals | 8 | 160 |
| Insulated M6 ring terminals | 9 | 90 |
| M6 flanged serrated nuts | 16  | 80 |
| Heat shrink 12 mm | 1 m | 100 |
| Automotive female terminals 6.3 mm | 10  | 50 |
| NSHVI ferrules (set) | 1 | 300 |
| Cable ties (pack) | 1 | 200 |
| **Total** | | **5 980** |

---

## Additional Expenses

| Component | Qty | Estimated Price (RUB) |
|---|-----|---|
| Cooling | — | 10 000 |
| Bearings | — | 5 000 |
| Cables, rods, belts and other possible components | — | 5 000 |
| **Total** | | **20 000** |

---

## Summary Purchase List

```
Motors:
1. BLDC 6384 120KV – 6 pcs
2. BLDC 5065 140KV – 7 pcs
3. BLDC 5010 360KV – 10 pcs
4. BLDC 3205 110KV – 13 pcs
5. Needle roller 4×6 mm G3 - 300 pcs
6. Needle roller 8×8 mm G3 - 300 pcs

Drivers:
1. ODrive 3.6 – 3 pcs
2. Hoverboard mainboards – 9 pcs
3. SimpleFOCMini – 13 pcs

Sensors:
1. MT6826S – 36 pcs
2. ICM-20948 – 1 pc
3. BMI160 – 20 pcs
4. FSR402 – 10 pcs
5. XNQJALYCY 100 kg – 4 pcs
6. Dual HD USB Camera – 1 pc

Support ICs:
1. CD74HC4067 – 2 pcs
2. HX711 – 4 pcs
3. GPIO expansion for ESP32 – 1 pc
4. SN65HVD230 – 20 pcs

Low‑level MCUs:
1. STM32F103C8T6 – 10 pcs
2. AT32F403ACGU7 – 7 pcs
3. ESP32‑S3 N16R8 – 1 pc

High‑level brain:
1. Laptop Lenovo L7 / R9 / RTX 3080 / 32GB / 1TB – 1 pc

Display:
1. Flexible LED P1.53 320×160 mm – 1 pc

Battery:
1. Li‑NMC SK 3.7 V 80.5 Ah – 10 pcs
2. JK‑B2A24S20P BMS – 1 pc

Buck converters:
1. 1500 W – 1 pc
2. 600 W – 3 pcs

Cables:
1. KOG1-T 1×25 mm² – 3 m
2. KGTP‑HL 2×4 mm² – 10 m
3. KGTP‑HL 2×1.5 mm² – 10 m
4. MKEShng(A)‑LS 7×0.35 – 10 m
5. MKEShng(A)‑LS 5×0.35 – 10 m
6. MKEShng(A)‑LS 2×0.35 – 5 m
7. MGShV 0.35 – 20 m
8. 14 AWG – 50 m
9. 20 AWG – 50 m
10. 26 AWG – 50 m
11. 30 AWG – 100 m

Capacitors & resistors:
1. 63 V 4 700 µF – 10 pcs
2. 35 V 2 200 µF – 15 pcs
3. 50 V 0.1 µF – 100 pcs
4. Resistor kit – 1 set
5. LC filter 50V 4A – 1 pc
6. LC filter 50V 20A – 1 pc

Connectors / distributors:
1. Distribution block 250 A – 2 pcs
2. WAGO 5‑way – 6 pcs
3. WAGO 3‑way – 2 pcs
4. QS8P‑S – 1 pair
5. XT90 – 6 pairs
6. XT60 – 12 pairs
7. XT30 – 5 pairs
8. GX12 – 5 pairs
9. JST‑XH 2.54 mm – 1 set

Fuses:
1. DC breaker 200 A – 1 pc
2. Fuse hub 10‑slot – 1 pc
3. 40 A ATO – 7 pcs (lot of 30)
4. 25 A ATO – 2 pcs (lot of 30)
5. 10 A ATO – 1 pc (lot of 30)
6. Single holder + 80 A fuse – 3 pcs
7. Ideal diode module 80V 50A - 1 pc

Fasteners:
1. Unaccounted – ? pcs
2. TML 10‑6 – 8 pcs
3. M6 ring terminals – 9 pcs
4. M6 flanged nuts – 16 pcs
5. Heat shrink 12 mm – 1 m
6. Female terminals 6.3 mm – 10 pcs
7. NSHVI ferrules – 1 set
8. Cable ties – 1 pack

Materials:
1. PETG – 10 kg
2. TPU A95 – 2 kg
3. Platinum‑cure silicone – 10 kg
4. Electrocorundum 25A M2.5 F2500 – 4 kg
5. PETG GF15 – 3 kg
6. PETG CFF M405 – 1 kg
7. PETG CF15 – 3 kg
```

---

## Final Cost Summary

| Category | Total (RUB) |
| --- | --- |
| **Motors** | 60 370 |
| **Drivers** | 26 315 |
| **Sensors** | 22 180 |
| **Brains & Logic** | 92 745 |
| **Battery & Power** | 40 000 |
| **Cables** | 11 095 |
| **Connectors & Distributors** | 4 878 |
| **Fuses & Protection** | 4 303 |
| **Capacitors & Filtering** | 2 397 |
| **Display** | 5 500 |
| **Plastics & Materials** | 36 570 |
| **Fasteners** | 5 980 |
| **Additional Expenses** | 20 000 |
| **TOTAL** | **332 333 RUB** |

*All prices are approximate and may vary depending on exchange rates and seller availability.*

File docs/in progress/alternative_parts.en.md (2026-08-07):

# Alternative Parts — Open-Humanoid-180

> **Status:** work in progress.
>
> Budget‑friendly substitutes and fallback components in case primary parts become unavailable.

## Planned Content

- Replacements for 6384 / 5065 / 3205 motors (different KV, other brands).
- Alternatives to ODrive3.6 (VESC, MKS XDrive, DIY).
- Hoverboard ESC substitutes (other FOC‑capable ESCs).
- Alternative encoders (AS5047, TLE5012 as MT6826S replacements).
- Material alternatives: PA12‑CF → PETG+CF, aluminium → steel / printed parts.
- Where to source cheap components (scavenging from robot vacuums, e‑scooters).

## Status

This document will be updated as:
- Alternative components are tested.
- Supply shortages or high prices are identified for primary parts.

---

*Available now: [BOM.en.md](BOM.en.md), [power_schematic.en.md](power_schematic.en.md), [weight_budget.en.md](weight_budget.en.md)*

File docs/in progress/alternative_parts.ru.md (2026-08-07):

# Запасные варианты компонентов — Open-Humanoid-180

> **Статус:** в разработке.
>
> Бюджетные альтернативы и запасные варианты на случай недоступности основных компонентов.

## Планируемое содержание

- Замены для моторов 6384 / 5065 / 3205 (другие KV, другие производители).
- Альтернативы для ODrive3.6 (VESC, MKS XDrive, DIY).
- Замена плат гироскутеров (другие ESC с FOC).
- Альтернативные энкодеры (AS5047, TLE5012 вместо MT6826S).
- Замена материалов: PA12‑CF → PETG+CF, алюминий → сталь/печать.
- Где брать компоненты дёшево (разборка старых роботов-пылесосов, электросамокатов).

## Статус

Документ будет заполняться по мере:
- Тестирования альтернативных компонентов.
- Выявления дефицита или дороговизны основных позиций.

---

*Пока доступны: [BOM.ru.md](BOM.ru.md), [power_schematic.ru.md](power_schematic.ru.md), [weight_budget.ru.md](weight_budget.ru.md)*

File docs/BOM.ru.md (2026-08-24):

# Смета компонентов (BOM) — Open-Humanoid-180

Все цены указаны в российских рублях (₽) по состоянию на июль-август 2026 года с учётом доставки (доставка считается, если сразу брать нужное количество одного типа деталей).

---

## Моторы и приводы

| Компонент | Кол‑во | Цена за шт (₽) | Итого (₽) | Ссылка |
| :--- | :----: | :---: | :---: | :--- |
| BLDC 6384 120KV | 6 | 4 000 |  24 000 | [Ozon](https://www.ozon.ru/product/elektricheskiy-balansirovochnyy-samokat-skeytbord-6384-120kv-bez-datchika-3607953100/) |
| BLDC 5065 140KV | 7 | 2 700 |  18 900 | [Ozon](https://www.ozon.ru/product/diy-n5065-140kv-bldc-besshchetochnyy-dvigatel-dlya-elektroskutera-bezdatchikovyy-1986965132/) |
| BLDC 5010 360KV | 10 | 1 000 |  10 000 | [Ozon](https://www.ozon.ru/product/besshchetochnye-dvigateli-5010-360-kv-s-vysokim-krutyashchim-momentom-dlya-razlichnyh-4198584996/) |
| BLDC 3205 110KV | 13 | 360 | 4 680 | [AliExpress](https://aliexpress.ru/item/1005010807047447.html) |
| Ролик игольчатый 4х6 мм G3 |  300 | 3.5 | 1 050 | [Русмет](https://www.tdrusmet.ru/roliki/4x6mm-g3-rolik?sort=p.price&order=ASC&limit=100) |
| Ролик игольчатый 8х8 мм G3 |  300 | 5.8 | 1 740 | [Русмет](https://www.tdrusmet.ru/8x8mm-g3-rolik) |

---

## Драйверы моторов

| Компонент | Кол‑во |  Цена за шт (₽) | Итого (₽) | Ссылка |
| :--- | :----: | :---: | :---: | :--- |
| ODrive 3.6 (клон) | 3 | 3 400 |  10 200 | [Ozon](https://www.ozon.ru/product/foc-bldc-dual-motor-controller-xdrive-xdrive3-6-apgreyd-kit-56v-dlya-servo-vysokotochnyy-na-5046874017/) |
| Плата гироскутера (2 канала) | 9 | 1 500 |  13 500 | [Avito](https://www.avito.ru/ekaterinburg/sport_i_otdyh/platy_upravleniya_giroskutera_42v_8164713218) (б/у) |
| SimpleFOCMini (MS8313) | 13 | 185 (255 за 1 шт) | 2 615 | [AliExpress](https://aliexpress.ru/item/1005008486050546.html) (лот 10 шт + 1 шт) |

---

## Датчики

| Компонент | Кол‑во | Цена за шт (₽) | Итого (₽) | Ссылка |
| :--- | :----: | :---: | :---: | :--- |
| Магнитный энкодер MT6826S | 36 | 280 |  10 080 | [AliExpress](https://aliexpress.ru/item/1005008498235469.html) |
| Датчик давления FSR402 | 10 | 180 | 1 800 | [AliExpress](https://aliexpress.ru/item/4001062799587.html) |
| 9-осевой IMU ICM-20948 | 1 | 660 | 660 | [Ozon](https://www.ozon.ru/product/k2-20948-malomoshchnyy-9-osevoy-mems-datchik-otslezhivaniya-dvizheniya-ozy2-4015404965/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) |
| 6‑осевой IMU BMI160 | 20 | 90 | 1 800 | [Ozon](https://www.ozon.ru/product/10-komplektov-bmi160-gy-bmi160-6dof-6-osevoy-modul-datchika-akselerometra-1726319765/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) (лот 10 шт) |
| Тензодатчик 100 кг XNQJALYCY | 4 | 230 | 920 | [AliExpress](https://aliexpress.ru/item/1005006769729312.html) (лот 4 шт) |
| АЦП HX711 | 4 | 42 (лот 10 шт: 420) | 420 | [AliExpress](https://aliexpress.ru/item/1005009105560158.html) (лот 10 шт) |
| Dual HD USB‑камера (OV4689)  | 1 | 6 500 | 6 500 | [AliExpress](https://aliexpress.ru/item/1005010126423504.html) |

---

## Мозги и логика

| Компонент | Кол‑во | Цена за шт (₽) | Итого (₽) | Ссылка |
| :--- | :----: | :---: | :---: | :--- |
| Ноутбук Lenovo L7 / R9 / RTX 3080 / 32GB / 1TB (б/у) | 1 | 86 000 |  86 000 | [Avito](https://www.avito.ru/moskva/noutbuki/noutbuk_lenovo_l7_r9_rtx_3080_32gb_1tb_8203230225) |
| ESP32‑S3 N16R8 | 1 | 410 | 410 | [AliExpress](https://aliexpress.ru/item/1005009303526431.html) |
| Плата расширения GPIO для ESP32‑S3 | 1 | 355 | 355 | [AliExpress](https://aliexpress.ru/item/1005009799215827.html) |
| AT32F403ACGU7 | 7 | 340 | 2 380 | [AliExpress](https://aliexpress.ru/item/1005004842376803.html) |
| STM32F103C8T6 | 10 | 150 | 1 500 | [AliExpress](https://aliexpress.ru/item/1005001892019439.html?sku_id=12000018034505390) |
| CAN‑трансивер SN65HVD230 | 20 | 100 | 2 000 | [AliExpress](https://aliexpress.ru/item/1005008710123474.html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) |
| Аналоговый мультиплексор CD74HC4067 | 2 | 50 | 100 | [AliExpress](https://aliexpress.ru/item/1005005507548696.html) |

---

## Батарея и питание

| Компонент | Кол‑во | Цена за шт (₽) | Итого (₽) | Ссылка |
| :--- | :----: | :---: | :---: | :--- |
| Li‑NMC SK 3,7 В 80,5 А·ч | 10 | 3 000 |  30 000 | [Avito](https://www.avito.ru/sankt-peterburg/orgtehnika_i_rashodniki/litiy-ionnye_yacheyki_li-nmc_sk_37v_805ah_8259027903) |
| JK-B2A24S20P Smart BMS (8S-24S, 200 А) | 1 | 7 000 | 7 000 | [AliExpress](https://aliexpress.ru/item/1005011930339277.html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) |
| Понижайка 1500 Вт (28,8→19,5 В) | 1 | 1 500 | 1 500 | [AliExpress](https://aliexpress.ru/item/1005009348542795.html) |
| Понижайка 600 Вт (28,8→5 В) | 3 | 500 | 1 500 | [Ozon](https://www.ozon.ru/product/dc-dc-ponizhayushchiy-preobrazovatel-600-vt-stabilizator-2635865398/) |

---

## Провода и кабели

| Компонент | Кол‑во | Цена за м (₽) | Итого (₽) | Ссылка |
| :--- | :----: | :---: | :---: | :--- |
| КОГ1-Т 1×25 мм² |  3 м | 200 | 600 | [N-Kabel](https://nn.n-kabel.ru/position/kog1_t_1h25/) |
| КГТП‑ХЛ 2×4 мм² |  10 м  | 121,66 | 1 217 | [Cable‑ES](https://cable-es.ru/catalog/kgtp-hl/kgtp-hl-2h4/) |
| КГТП‑ХЛ 2×1,5 мм² |  10 м  | 49,73 | 497 | [Cable‑ES](https://cable-es.ru/catalog/kgtp-hl/kgtp-hl-2h1-5/) |
| МКЭШнг(А)‑LS 7×0,35 мм² |  10 м  | 76,42 | 765 | [Cable‑ES](https://cable-es.ru/catalog/mkeshng-ls/mkeshng-a-ls-7h0-35/) |
| МКЭШнг(А)‑LS 5×0,35 мм² |  10 м  | 60,24 | 603 | [Cable‑ES](https://cable-es.ru/catalog/mkeshng-ls/mkeshng-a-ls-5h0-35/) |
| МКЭШнг(А)‑LS 2×0,35 мм² |  5 м | 34,18 | 171 | [Cable‑ES](https://cable-es.ru/catalog/mkeshng-ls/mkeshng-a-ls-2h0-35/) |
| МГШВ 0,35 мм² |  20 м  | 7,12 | 142 | [Cable‑ES](https://cable-es.ru/catalog/mgshv/mgshv-0-35/) |
| 14 AWG |  50 м  | 75 | 3 750 | [Ozon](https://www.ozon.ru/product/silikonovyy-elektricheskiy-provod-awg-14-2-08mm-1-1-metr-chernyy-krasnyy-769143306/) |
| 20 AWG |  50 м  | 30 | 1 500 | [Ozon](https://www.ozon.ru/product/20awg-5-tsvetov-po-10-metrov-nabor-silikonovyh-mnogozhilnyh-provodov-3466223449/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) |
| 26 AWG |  50 м  | 16 | 800 | [Ozon](https://www.ozon.ru/product/nabor-provodov-dlya-payki-2375724297/) |
| 30 AWG | 100 м  | 10,5 | 1050 | [Ozon](https://www.ozon.ru/product/nabor-silikonovyh-mnogozhilnyh-provodov-30awg-5-tsvetov-po-20-metrov-1630156271/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) |

---

## Разъёмы, клеммы, распределители

| Компонент |  Кол‑во  | Цена за шт (₽) | Итого (₽) | Ссылка |
| :--- | :---: | :---: | :---: | :--- |
| Блок распределительный 250 А (11 выводов) | 2 | 788 | 1 576 | [Ozon](https://www.ozon.ru/product/blok-raspredelitelnyy-kbr-rbd-250-250a-12-prisoedineniy-dekron-4045680559/) |
| WAGO 221‑415 (5 контактов) | 6 | 44 | 264 | [Ozon](https://www.ozon.ru/product/klemma-wago-221-415-5-provodnaya-dlya-soedineniya-provodov-10-sht-2008848825/) |
| WAGO 221‑413 (3 контакта) | 2 | 39 | 78 | [Ozon](https://www.ozon.ru/product/klemma-wago-221-413-3-h-provodnaya-dlya-soedineniya-provodov-vago-10-sht-2008848822/) |
| QS8P‑S (Anti‑Spark) |  1 пара  | 682 | 682 | [Ozon](https://www.ozon.ru/product/razem-dlya-modifikatsii-akkumulyatora-elektromobilya-qs8p-l-vysokotochnyy-razem-dlya-zashchity-3302358304/) |
| XT90 (лот 5 пар) |  6 пар | 118,4 | 710 | [Ozon](https://www.ozon.ru/product/konnektor-silovoy-xt90-m-f-razem-papa-mama-5-par-amass-1410065195/) |
| XT60 (лот 5 пар) |  12 пар  | 30,6 | 367 | [AliExpress](https://aliexpress.ru/item/33061763696.html) |
| XT30 (лот 5 пар) |  5 пар | 30,2 | 151 | [AliExpress](https://aliexpress.ru/item/33061763696.html) |
| XT60h (лот 5 пар, опционально) | — | 61,8 | — | [AliExpress](https://aliexpress.ru/item/1005007299555986.html) |
| GX12 (5‑pin) |  5 пар | ~150 | 750 | *(generic)* |
| JST‑XH 2,54 мм | 1 компл. | ~300 | 300 | *(generic)* |

---

## Предохранители и защита

| Компонент | Кол‑во |  Цена за шт (₽)  | Итого (₽) | Ссылка |
| :--- | :----: | :---: | :---: | :--- |
| Автомат DC 200 А | 1 | 2 400 | 2 400 | [AliExpress](https://aliexpress.ru/item/1005005566503592.html) |
| Хаб предохранителей (10 гнёзд) | 1 | 640 | 640 | [AliExpress](https://aliexpress.ru/item/1005005781273635.html) |
| Предохранитель ATO 40 А | 7 | 1,2 (лот 30 шт)  | 36 (лот)  | [Ozon](https://www.ozon.ru/product/predohranitel-avtomobilnyy-30-sht-art-40a-4633025301/) |
| Предохранитель ATO 25 А | 2 | 2,63 (лот 30 шт) | 79 (лот)  | [Ozon](https://www.ozon.ru/product/predohranitel-avtomobilnyy-30-sht-art-25a-4633034058/) |
| Предохранитель ATO 10 А | 1 | 1,96 (лот 30 шт) | 59 (лот)  | [Ozon](https://www.ozon.ru/product/predohranitel-avtomobilnyy-30-sht-art-10a-4633021334/) |
| Одиночный держатель + предохр. 80 А (для ODrive) | 3 | 163 | 489 | [AliExpress](https://aliexpress.ru/item/1005005850402237.html) |
| Модуль идеального диода 80В 50А | 1 | 600 | 600 | [Ozon](https://www.ozon.ru/product/modul-idealnogo-dioda-s-vysokim-tokom-80v-50a-s-klemmoy-4840017570/?sh=HZL6ZeYCXw) |

---

## Конденсаторы и фильтрация

| Компонент | Кол‑во | Цена за шт (₽) | Итого (₽) | Ссылка |
| :--- | :----: | :---: | :---: | :--- |
| Алюминиевый конденсатор 63 В 4 700 мкФ | 10 | 92,5 | 925 | [AliExpress](https://aliexpress.ru/item/1005005776158492.html?sku_id=12000034312209898) (лот 2 шт) |
| Алюминиевый конденсатор 35 В 2 200 мкФ | 15 | 26,8 | 401 | [AliExpress](https://aliexpress.ru/item/1005003663338815.html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) (лот 5 шт) |
| Керамический конденсатор 50 В 0,1 мкФ (104) |  100 | 1,01 | 101 | [AliExpress](https://aliexpress.ru/item/4000368078609.html) (лот 100 шт) |
| Набор резисторов VKTECH 300 шт | 1 | 320 | 320 | [AliExpress](https://aliexpress.ru/item/1005009483805314.html) |
| LC-фильтр помех 50В 4А | 1 | 150 | 150 | [Ozon](https://www.ozon.ru/product/plata-filtra-pitaniya-postoyannogo-toka-podavlenie-pomeh-dlya-istochnika-pitaniya-0-50v-2a-3a-4a-3280420183/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) |
| LC-фильтр помех 50В 20А | 1 | 500 | 500 | [Ozon](https://www.ozon.ru/product/avtomobilnyy-emi-filtr-dlya-audiosistemy-20-a-3287207466/?sh=HZL6ZV56Kg) |

---

## Экран и визуализация

| Компонент | Кол‑во | Цена за шт (₽) | Итого (₽) | Ссылка |
| :--- | :----: | :---: | :---: | :----- |
| Гибкий LED P1.53 320×160 мм (209×104) | 1 | 5 500 |  5 500 | [AliExpress](https://aliexpress.ru/item/1005008740646437.html) |

---

## Пластик и материалы

| Компонент | Кол‑во | Цена за ед. (₽) | Итого (₽) | Ссылка |
| :--- | :----: | :---: | :---: | :--- |
| PETG (Гексалит, 5 кг × 2) | 10 кг  | 600/кг | 6 000 | [Ozon](https://www.ozon.ru/product/petg-chernyy-plastik-dlya-3d-pechati-geksalit-1-75mm-5-motkov-filamenta-po-1-kg-2425802879/) |
| TPU A95 (Elegoo) |  2 кг  | 1 160/кг | 2 320 | [AliExpress](https://aliexpress.ru/item/1005007342881359.html) |
| PETG GF15 |  3 кг  | 1 100/кг | 3 300 | [Ozon](https://www.ozon.ru/product/petg-gf-plastik-dlya-3d-printera-chernyy-armirovannyy-steklovoloknom-300-13-mkm-15-4355981121/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) |
| PETG CFF M405 |  1 кг  | 1 900/кг | 1 900 | [Ozon](https://www.ozon.ru/product/petg-plastik-u3-cff-m-405-dlya-3d-pechati-inzhenernyy-professionalnyy-chernyy-1kg-764551726/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) |
| PETG CF15 |  3 кг  | 1 550/кг | 4 650 | [Ozon](https://www.ozon.ru/product/prizm-petg-cf-carbon-fiber-plastik-1-75-mm-1-kg-chernyy-3613193935/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) |
| Двухкомпонентный силикон на платиновом катализаторе | 10 кг  | ~1 500/кг |  15 000 | *(generic)* |
| Электрокорунд 25A М2.5 F2500 |  4 кг  | 850/кг | 3 400 | [Ozon](https://www.ozon.ru/product/sk-mineral-abraziv-dlya-peskostruynyh-apparatov-1-l-1000-g-1-sht-1415226313/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) |

---

## Крепёж и мелочи

| Компонент | Кол‑во | Оценочная цена (₽) |
| :--- | :----: | :---: |
| Неучтённый | — | 5 000 |
| Наконечники ТМЛ 10‑6 | 8 | 160 |
| Клеммы кольцевые изолированные М6  | 9 | 90 |
| Гайки фланцевые М6 с насечкой | 16 | 80 |
| Термоусадка 12 мм |  1 м | 100 |
| Клеммы автомобильные «мама» 6,3 мм | 10 | 50 |
| Гильзы НШВИ (набор) | 1 | 300 |
| Кабельные стяжки (пачка) | 1 | 200 |
| **Итого** | | **~5 980** |

---

## Дополнительные траты

| Компонент | Кол‑во | Оценочная цена (₽) |
| :--- | :----: | :---: |
| Охлаждение | — | 10 000 |
| Подшипники | — | 5 000 |
| Тросы, тяги, ремни<br>и другие возможные<br>компоненты | — | 5 000 |
| **Итого** | | **~20 000** |

---

## Сводный список закупок

```
Моторы:
1. BLDC 6384 120KV – 6 шт
2. BLDC 5065 140KV – 7 шт
3. BLDC 5010 360KV – 10 шт
4. BLDC 3205 110KV – 13 шт
5. Ролик игольчатый 4х6 мм G3 - 300 шт
6. Ролик игольчатый 8х8 мм G3 - 300 шт

Драйверы:
1. ODrive 3.6 – 3 шт
2. Платы гироскутеров – 9 шт
3. SimpleFOCMini – 13 шт

Датчики:
1. MT6826S – 36 шт
2. ICM-20948 - 1 шт
3. BMI160 - 20 шт
4. FSR402 – 10 шт
5. XNQJALYCY 100 кг – 4 шт
6. Dual HD USB Camera – 1 шт

Обвязка:
1. CD74HC4067 – 2 шт
2. HX711 – 4 шт
3. Плата расширения GPIO ESP32 – 1 шт
4. SN65HVD230 – 20 шт

Нижний уровень мозгов:
1. STM32F103C8T6 - 10 шт
2. AT32F403ACGU7 – 7 шт
3. ESP32‑S3 N16R8 – 1 шт

Верхний уровень мозгов:
1. Ноутбук Lenovo L7 / R9 / RTX 3080 / 32GB / 1TB – 1 шт

Визуал:
1. Гибкий LED P1.53 320×160 мм – 1 шт

Батарея:
1. Li‑NMC SK 3,7 В 80,5 А·ч – 10 шт
2. JK‑B2A24S20P BMS – 1 шт

Понижайки:
1. 1500 Вт – 1 шт
2. 600 Вт – 3 шт

Кабели:
1. КОГ1-Т 1×25 мм² – 3 м
2. КГТП‑ХЛ 2×4 мм² – 10 м
3. КГТП‑ХЛ 2×1,5 мм² – 10 м
4. МКЭШнг(А)‑LS 7×0,35 – 10 м
5. МКЭШнг(А)‑LS 5×0,35 – 10 м
6. МКЭШнг(А)‑LS 2×0,35 – 5 м
7. МГШВ 0,35 – 20 м
8. 14 AWG – 50 м
9. 20 AWG – 50 м
10. 26 AWG – 50 м
11. 30 AWG - 100 м

Конденсаторы и фильтрация:
1. 63 В 4 700 мкФ – 10 шт
2. 35 В 2 200 мкФ – 15 шт
3. 50 В 0,1 мкФ – 100 шт
4. Резисторы – 1 набор
5. LC-фильтр помех 50В 4А - 1 шт
6. LC-фильтр помех 50В 20А - 1 шт

Штекеры/разъёмы/распределители:
1. Блок распределительный 250 А – 2 шт
2. WAGO 5 контактов – 6 шт
3. WAGO 3 контакта – 2 шт
4. QS8P‑S – 1 пара
5. XT90 – 6 пар
6. XT60 – 12 пар
7. XT30 – 5 пар
8. GX12 – 5 пар
9. JST‑XH 2,54 мм – 1 комплект

Предохранители:
1. Автомат 200 А – 1 шт
2. Хаб на 10 гнёзд – 1 шт
3. 40 А ATO – 7 шт (лот 30 шт)
4. 25 А ATO – 2 шт (лот 30 шт)
5. 10 А ATO – 1 шт (лот 30 шт)
6. Одиночные держатели с предохр. 80 А – 3 шт
7. Модуль идеального диода 80В 50А - 1 шт

Крепёж:
1. Неучтённый - ? шт
2. ТМЛ 10‑6 – 8 шт
3. Клеммы кольцевые М6 – 9 шт
4. Гайки фланцевые М6 – 16 шт
5. Термоусадка 12 мм – 1 м
6. Клеммы «мама» 6,3 мм – 10 шт
7. Гильзы НШВИ – 1 набор
8. Кабельные стяжки – 1 пачка

Материалы:
1. PETG – 10 кг
2. TPU A95 – 2 кг
3. Силикон на платиновом катализаторе – 10 кг
4. Электрокорунд 25A М2.5 F2500 - 4 кг
5. PETG GF15 - 3 кг
6. PETG CFF M405 - 1 кг
7. PETG CF15 - 3 кг
```

---

## Итоговая стоимость

| Категория | Итого (₽) |
| :--- | :---: |
| **Моторы** | 60 370 |
| **Драйверы** | 26 315 |
| **Датчики** | 22 180 |
| **Мозги и логика** | 92 745 |
| **Батарея и питание** | 40 000 |
| **Кабели** | 11 095 |
| **Разъёмы и распределители**  | 4 878 |
| **Предохранители** | 4 303 |
| **Конденсаторы и фильтрация** | 2 397 |
| **Экран** | 5 500 |
| **Пластик и материалы** | 36 570 |
| **Крепёж** | 5 980 |
| **Дополнительные траты** | 20 000 |
| **ИТОГО** | **332 333 ₽** |

*Цены являются приблизительными и могут меняться в зависимости от курса валют и наличия у продавцов.*

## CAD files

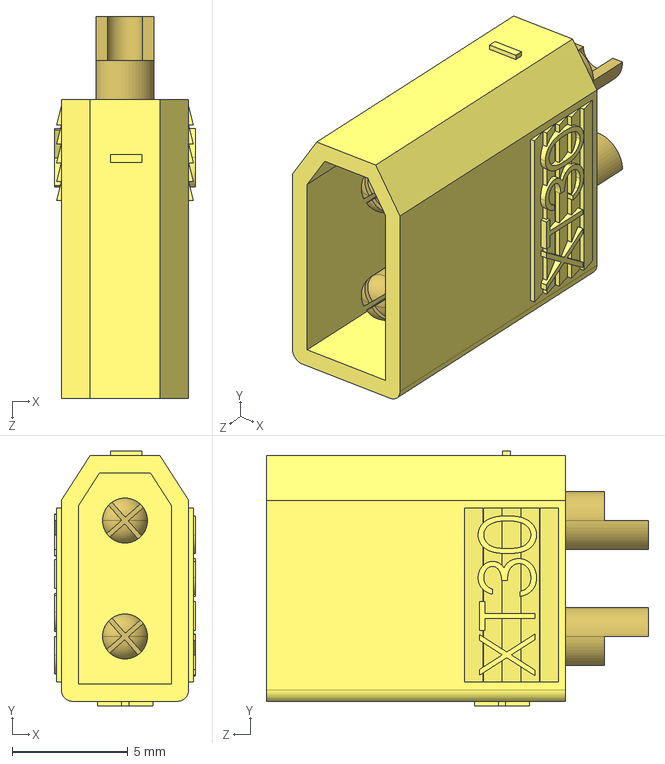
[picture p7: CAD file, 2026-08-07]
hardware/CAD/connectors/xt30/xt30-m.STEP
6.10 x 11.0 x 16.5 mm

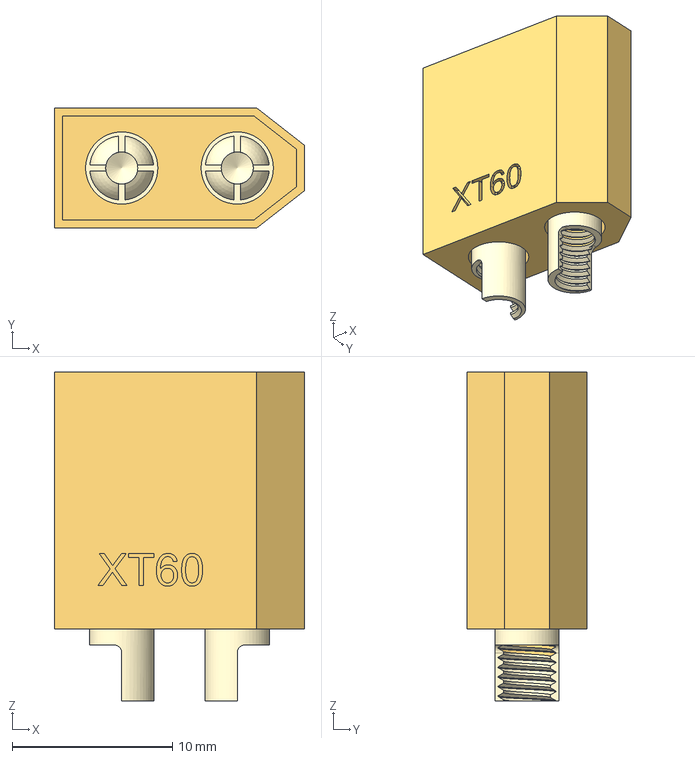
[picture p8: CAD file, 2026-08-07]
hardware/CAD/connectors/xt60/xt60-m.step
15.6 x 7.50 x 20.5 mm

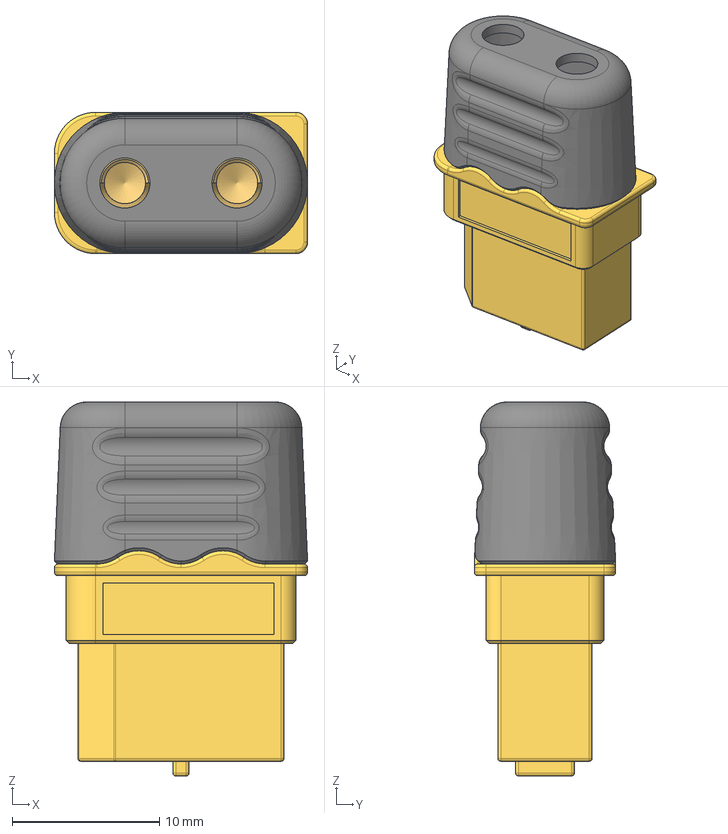
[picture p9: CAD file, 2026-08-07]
hardware/CAD/connectors/xt60h/xt60h-f.step
17.2 x 9.60 x 25.4 mm
Body004 (Mirror #1)

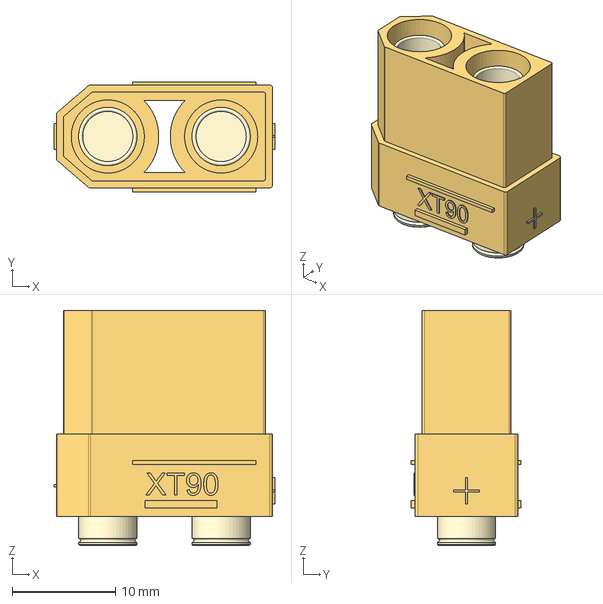
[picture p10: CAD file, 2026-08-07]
hardware/CAD/connectors/xt90/xt90-f.step
21.4 x 10.7 x 22.8 mm

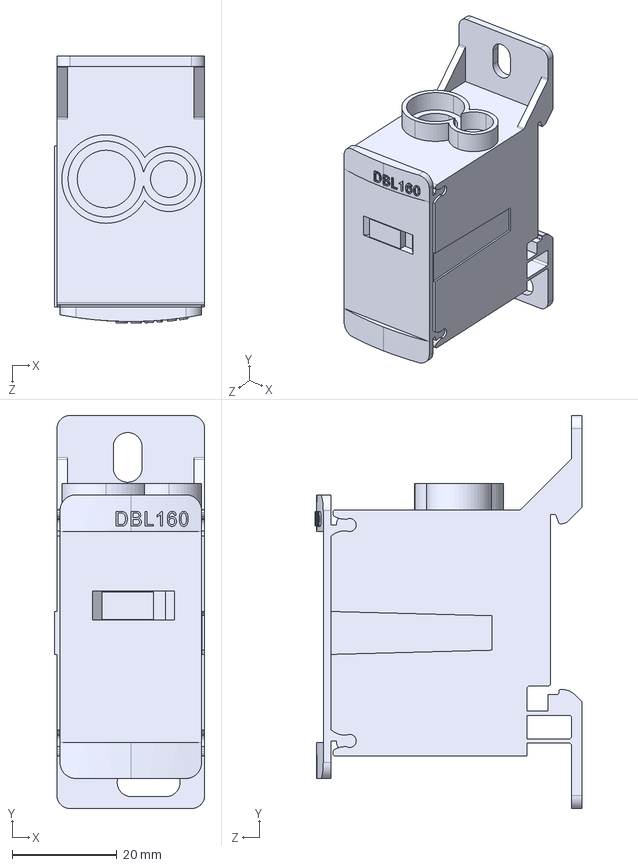
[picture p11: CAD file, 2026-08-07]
hardware/CAD/distribution/dbl160_distribution_block.step
28.7 x 75.0 x 51.0 mm

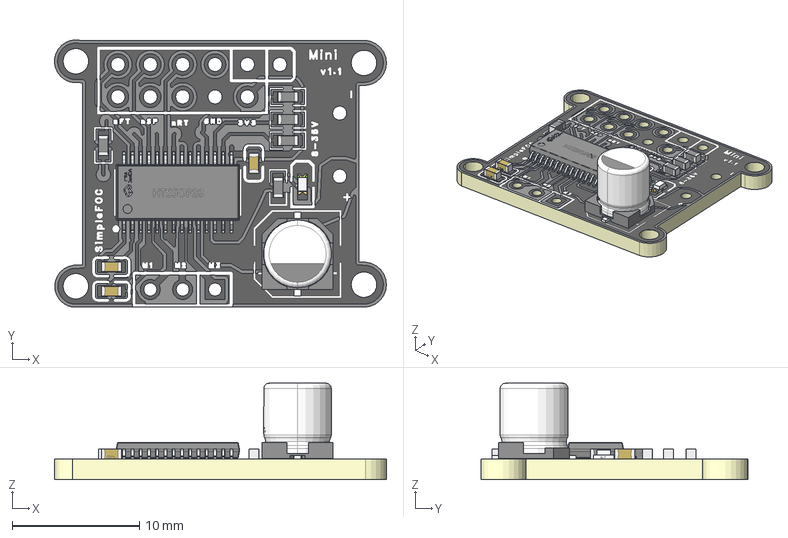
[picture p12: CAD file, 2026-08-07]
hardware/CAD/drivers/simplefocmini.step
26.1 x 21.0 x 7.59 mm
Board~auUg
TopCopper~auUg x 29
BottomCopper~auUg x 15
TopSilkscreen~auUg x 73
BottomSilkscreen~auUg x 120
TopFpcStiffener~auUg
BottomFpcStiffener~auUg
R0603~R0603_L1.6-W0.8-H0.8~auUg x 5
LED0603-R-RD~LED0603_L1.6-W0.8-H0.6~auUg
CAP-SMD_BD6.3-L6.6-W6.6-FD~CAP-SMD_L6.6-W6.6-H7.0-LS7.2~auUg
C0603~C0603_L1.6-W0.8-H0.8~auUg x 3
HTSSOP-28_L9.8-W4.5-P0.65-LS6.6-BL-EP~HTSSOP-28_ L9.7-W4.4-H1.2-LS6.4-P0.65~auUg

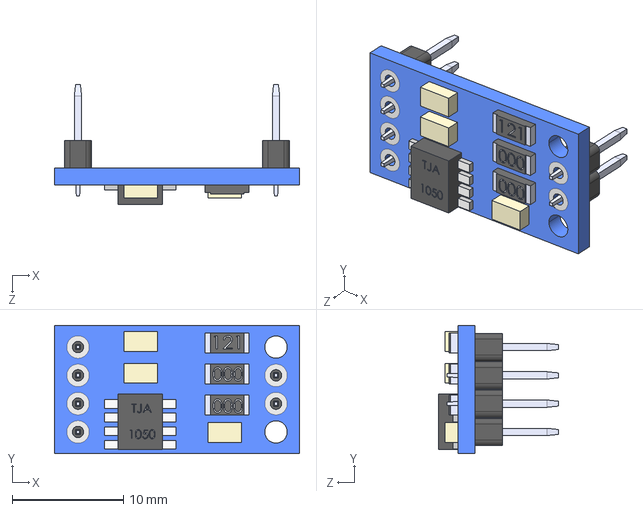
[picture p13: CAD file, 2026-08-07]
hardware/CAD/mcu/tja1050.STEP
22.0 x 11.5 x 10.8 mm

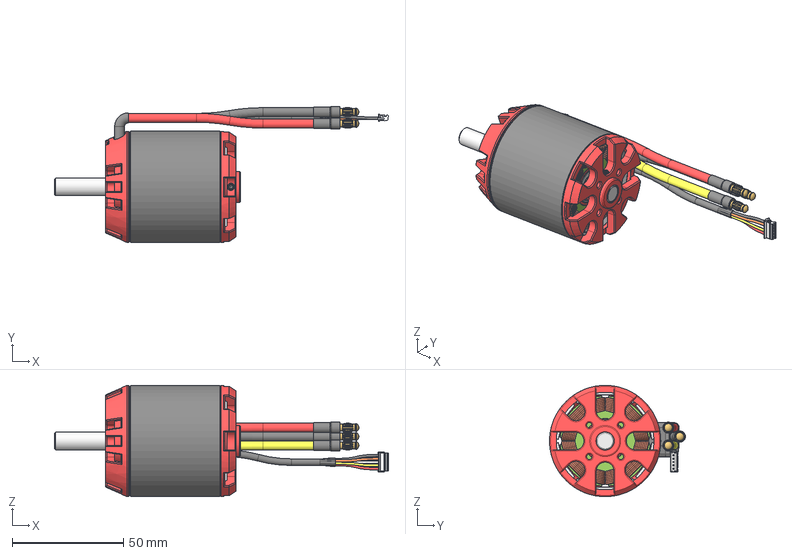
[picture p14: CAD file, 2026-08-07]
hardware/CAD/motors/5065-140KV.step
150.1 x 61.1 x 50.0 mm
M3x6-Screw

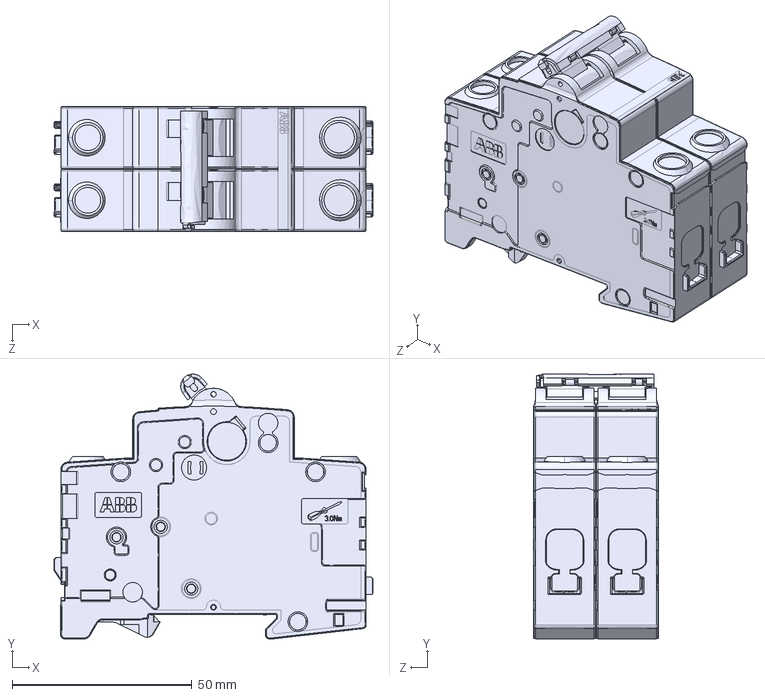
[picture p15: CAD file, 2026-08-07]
hardware/CAD/power/circuit_breaker_200a.STEP
88.8 x 73.7 x 34.8 mm

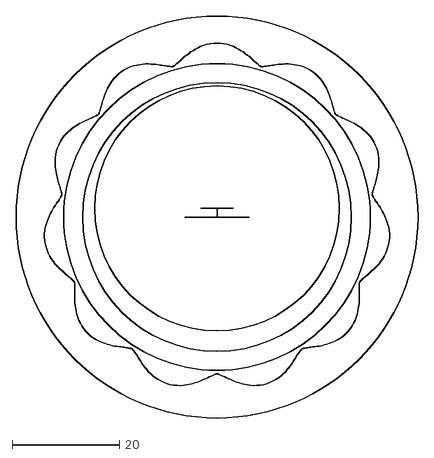
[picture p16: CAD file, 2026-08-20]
hardware/CAD/reducer_generator/vptc/10_8x8_75mm.dxf
75.0 x 75.0

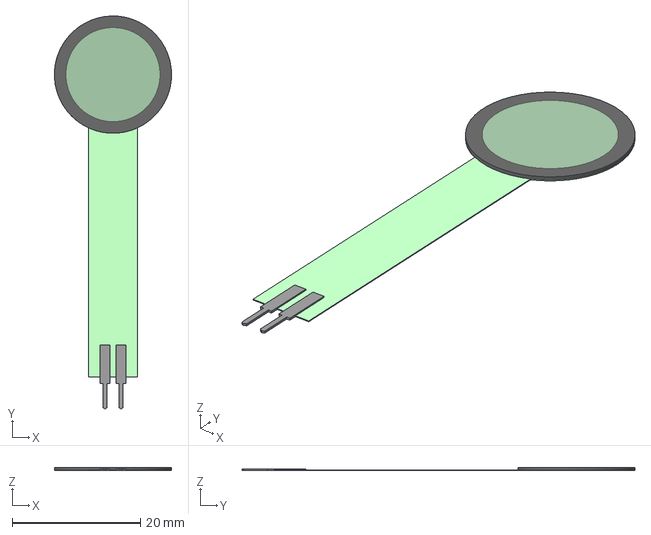
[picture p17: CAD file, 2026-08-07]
hardware/CAD/sensors/fsr402.step
18.3 x 61.3 x 0.5 mm

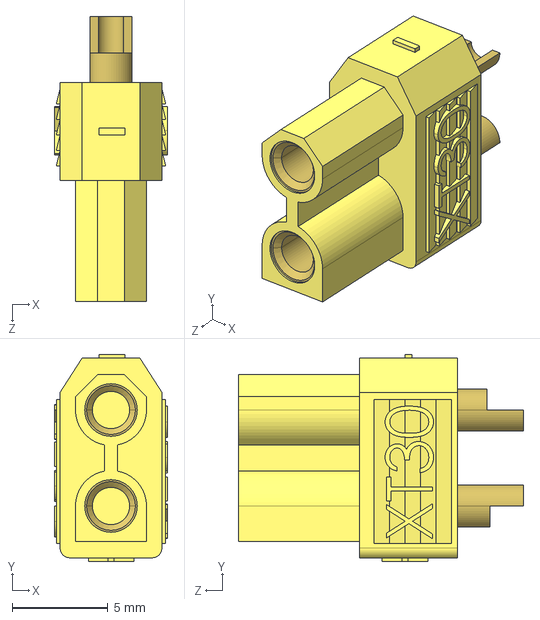
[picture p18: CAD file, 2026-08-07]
hardware/CAD/connectors/xt30/xt30-f.STEP
5.90 x 10.8 x 14.9 mm

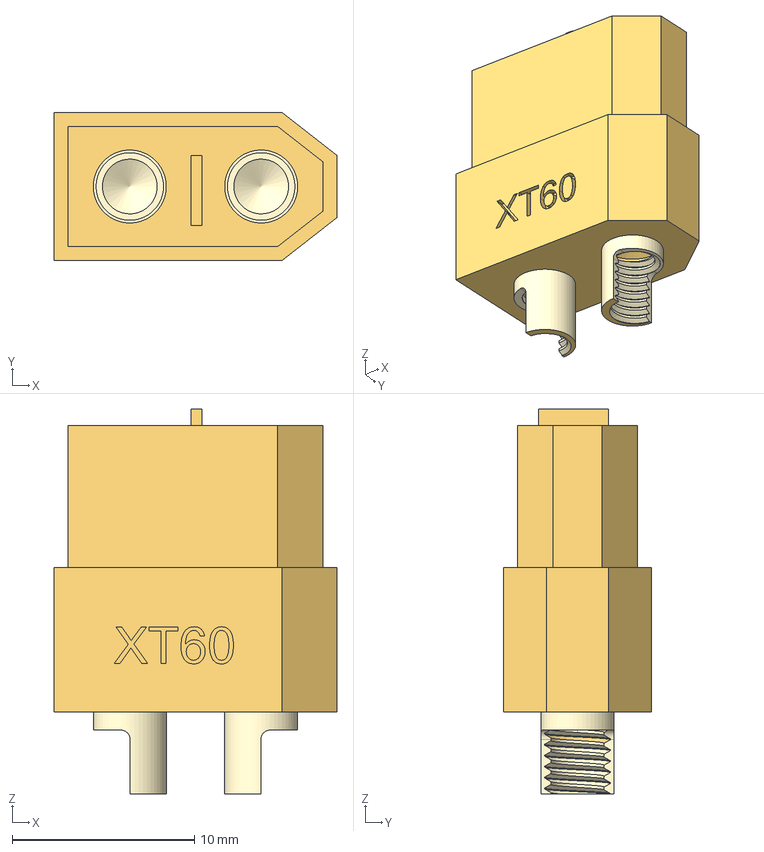
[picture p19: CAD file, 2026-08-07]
hardware/CAD/connectors/xt60/xt60-f.step
15.5 x 8.10 x 21.1 mm

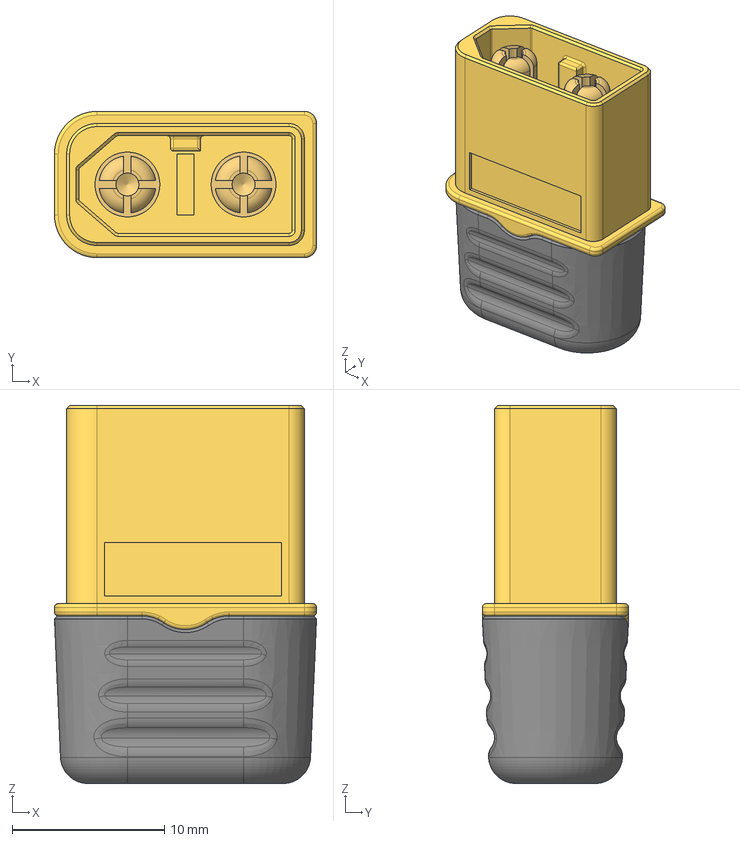
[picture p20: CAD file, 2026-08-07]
hardware/CAD/connectors/xt60h/xt60h-m.step
17.2 x 9.60 x 24.8 mm

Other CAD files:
hardware/CAD/connectors/xt90/XT90PB-M.step
hardware/CAD/drivers/odrive3.6.stp
hardware/CAD/mcu/txs0108e.step
hardware/CAD/motors/6384-120KV.step
hardware/CAD/mcu/cd74hc4067.stp
hardware/CAD/mcu/esp32-s3.step
hardware/CAD/motors/3205-110KV.step
hardware/CAD/power/ato_fuse_standard.stp
hardware/CAD/power/buck_300w_lm25116.step
hardware/CAD/power/fuse_holder_12slot.step
hardware/CAD/power/lifepo4_60145.stp
hardware/CAD/reducer_generator/vptc/7_4x6_28mm.dxf
hardware/CAD/reducer_generator/vptc/8_4x6_50mm.dxf.dxf
hardware/CAD/sensors/bmi160.step
hardware/CAD/sensors/ceramic_capacitor_104.step
hardware/CAD/sensors/hx711.STEP
hardware/CAD/sensors/mt6826s.stp
hardware/CAD/sensors/qmc5883l.step

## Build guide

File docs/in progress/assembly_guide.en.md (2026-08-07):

# Assembly Guide — Open-Humanoid-180

> **Status:** work in progress.
>
> Detailed step‑by‑step instructions for mechanical and electrical assembly of the robot.

## Planned Content

- Assembly sequence: from feet to head.
- Motor and reducer installation in each joint.
- Routing of power and signal harnesses inside limbs and torso.
- MKESH cable shielding rules and single‑point grounding.
- Installation of distribution blocks, WAGO terminals, and fuses.
- Final insulation and continuity checks.

## Status

This document will be completed after:
- First joint prototype is manufactured and tested.
- Assembly techniques are validated on a bench.

---

*Available now: [BOM.en.md](BOM.en.md), [power_schematic.en.md](power_schematic.en.md), [weight_budget.en.md](weight_budget.en.md)*

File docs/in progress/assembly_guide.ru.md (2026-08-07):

# Руководство по сборке — Open-Humanoid-180

> **Статус:** в разработке.
>
> Подробная инструкция по механической и электрической сборке робота.

## Планируемое содержание

- Последовательность сборки: от стоп к голове.
- Монтаж моторов и редукторов в суставы.
- Прокладка силовых и сигнальных жгутов внутри конечностей и корпуса.
- Правила экранирования кабелей МКЭШ и заземление в одной точке.
- Установка распределительных блоков, WAGO-клемм и предохранителей.
- Финальная проверка изоляции и контактных соединений.

## Статус

Документ будет заполнен после:
- Изготовления и тестирования первого прототипа сустава.
- Отработки технологии сборки на стенде.

---

*Пока доступны: [BOM.ru.md](BOM.ru.md), [power_schematic.ru.md](power_schematic.ru.md), [weight_budget.ru.md](weight_budget.ru.md)*

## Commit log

2026-08-07 Initial commit: full project structure with docs, hardware CAD, and READMEs
    [3205-110KV.step, 5065-140KV.step, 6384-120KV.step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]
2026-08-10 refactor: overhaul BOM spec with high-performance hardware and 2kWh NMC battery
    - Upgraded main MCU logic with AT32F403A and 3.3V TJA1042T CAN transceivers.
    - Replaced LiFePO4 battery setup with high-capacity NMC 7S 80.5Ah configuration (~2kWh)
    - Implemented MIDI/Mini-ANL bolt-on fuse protection for high-current ODrive lines.
    - Switched power rail system to high-voltage synchronous DC-DC buck converters (12-75V input).
    - Upgraded high-level compute module budget to RTX 3080 16GB laptop for local neural network inference.
    - Adjusted cable section with flexible copper wires and optimized plastic material volume.
2026-08-10 Update BOM with current pricing and purchase links
    - Recalculate totals for all categories based on actual July–August 2026 prices
    - Adjust quantities where lots are used (e.g., SimpleFOCMini, BMI160)
    - Update links for several components to working URLs
    - Total cost revised from ~291k to ~285.6k RUB
2026-08-10 docs: add kinematics documentation
    - Add kinematics.ru.md and kinematics.en.md with full DOF distribution
    - List all 36 joints, motor types (6384/5065/3205), and reduction ratios
    - Update README.md and README.en.md with links to kinematics files
    - Clarify hip (3 DOF per leg), waist (1 DOF), neck (3 DOF), shoulders (3 each),
    elbows (2 each with rotation), wrists (2 each), fingers (1 each)
    - Keep total motor count consistent (6 high + 17 medium + 13 basic)"
2026-08-11 feat: add reducer profile generator scripts (ПТК)
2026-08-12 docs(actuators): correct controller mapping for high/medium motors
    - Replace incorrect AT32 references with ODrive 3.6 and hoverboard boards
    - Keep SimpleFOCMini for basic motors
2026-08-12 docs: major BOM, kinematics and hardware updates
    - Motors:
    * Replaced some 5065 motors with 5010 360KV in hip rotation,
    shoulder rotation, elbow rotation and wrist joints
    * Updated motor count: 6384 (6), 5065 (7), 5010 (10), 3205 (13)
    * Total DoF remains 36
    - Wiring:
    * Switched phase wires from KGTP cables to 14 AWG silicone wire
    * Updated cable list in BOM accordingly
    - BOM:
    * Added second CD74HC4067 multiplexer (+1 pc)
    * Recalculated cable costs (now 11,398 RUB, previously 5,331 RUB)
    * Final total: 274,706 RUB (was 268,589 RUB)
    - Documentation:
    * Updated README.ru.md and README.en.md with new motor distribution
    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
2026-08-13 feat: generate test DXF profiles for 28mm, 50mm, and 63mm reducers & minor fixes
    [10_6x6_63mm.dxf, 7_4x6_28mm.dxf, 8_4x6_50mm.dxf.dxf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]
2026-08-13 minor fixes
    [vptc6.dxf]
2026-08-20 Refactor: 10S battery, CAN backbone (STM32+SN65HVD230), BOM & materials update
    [10_6x6_63mm.dxf, 10_8x8_75mm.dxf]
2026-08-24 fix: update weight in specifications to ~60 kg and add new components to the BOM
2026-08-24 fix: update motor specifications

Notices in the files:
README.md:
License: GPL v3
